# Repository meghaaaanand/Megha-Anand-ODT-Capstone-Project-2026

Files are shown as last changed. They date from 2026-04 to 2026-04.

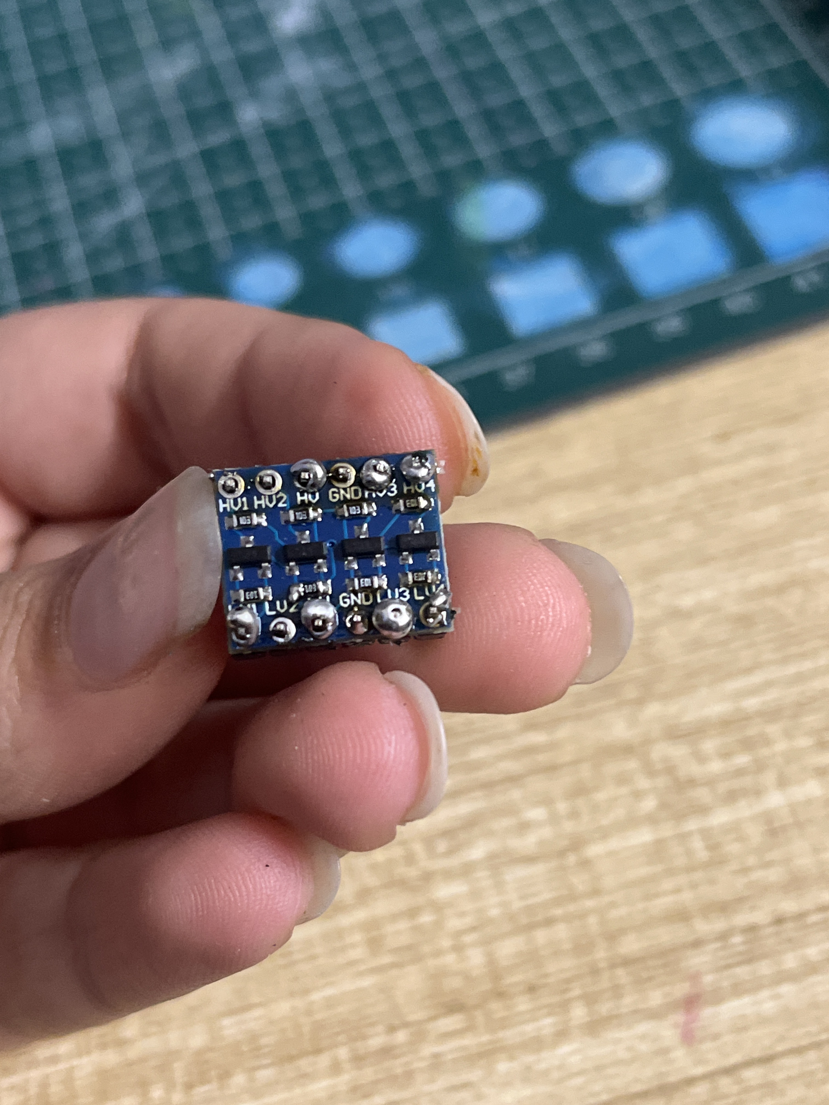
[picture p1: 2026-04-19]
Media/Week2/Pump Troubleshooting/1 Initial Logic Convertor solder.JPEG

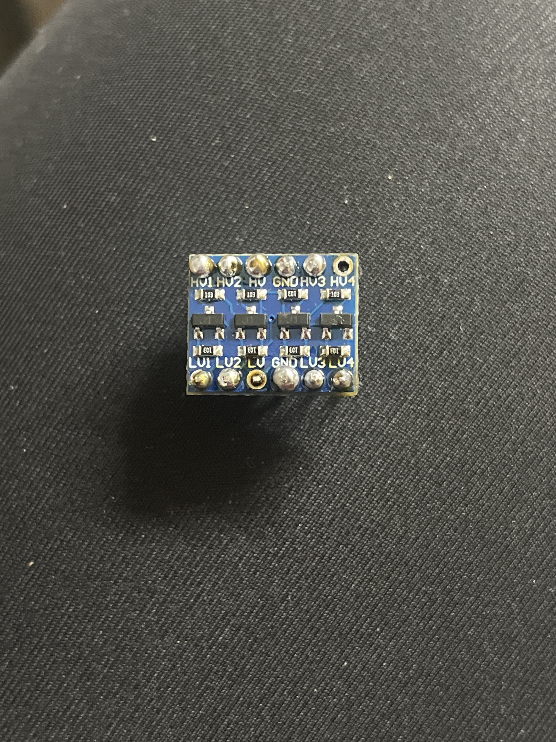
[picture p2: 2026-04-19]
Media/Week2/Pump Troubleshooting/2 Second solder.JPEG

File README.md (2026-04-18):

**Project Title**

Home Hydroponics System

**📌 Project Overview**

A compact vertical hydroponic system designed for home use, featuring a central pipe with angled plant spouts for efficient spatial distribution. Integrated perforated disc layers regulate staged water flow, improving nutrient delivery. Combined with embedded sensing and control, the system balances functionality, efficiency, and a clean, contemporary aesthetic.

**📂 Repository Structure**
1. Electronics Details
2. Mechanical Details
3. Software Details
4. Project Documents
5. Media

**⚙️ How to Navigate This Repository**

Electronics Details → Circuit Diagram, Components Justification

Mechanical Details → Sketches, CAD, and Fabrication Details

Software Details → Codes, Logic, and Implementation

Project Documents → Design thinking, Planning, Testing

Media → Weekly Progress and Final Output

**👥 Team Members**

Megha Anand & Siya Mittal

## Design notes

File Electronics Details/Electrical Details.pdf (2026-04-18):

# Electronic Details

## 1.Electronics Block Diagram

Attatched in seperate PDF file.

## 2.Components Table

Components | Quantity | Purpose | Justification
ESP32 | 1 | Central microcontroller to process sensor data and control system operations. | Provides sufficient GPIO pins, supports multiple sensors simultaneously, and enables real-time control (e.g., app/BLE integration).
Submersible Water Pump | 1 | Circulates nutrient-rich water through the hydroponic system. | Essential for maintaining continuous water flow, ensuring proper nutrient delivery to plants.
5V ,10A 1-Channel Relay Module | 1 | Switches the water pump ON/OFF using ESP32 signals. | Allows safe control of high-power devices (pump/mains) using low-voltage microcontroller output.
I2C Bi-Directional logic Level Converter- 4 Channel | 1 | Converts voltage levels between ESP32 (3.3V) and 5V components. | Prevents damage to ESP32 and ensures reliable communication with higher-voltage modules like the relay.
LDR Sensor | 3 | Detects light intensity at different levels of the structure. | Helps monitor light distribution across the system, enabling analysis of

| | | plant exposure and environmental conditions.
HC -SR04 | 1 | Measure water level in the reservoir. | Enables non -contact monitoring, preventing sensor damage and ensuring accurate water level detection.
DHT22 | 1 | Measures temperature and humidity of the environment. | Provides reliable environmental data critical for plant growth conditions.
Neo pixel | 1 | Provides visual feedback for system status (e.g., normal, warning, error). | Enhances user interaction and allows quick, intuitive understanding of system conditions without needing an interface.
Power Module | 1 | Supplies regulated power to components in the system. | Ensures stable voltage distribution, preventing fluctuations that could affect sensor readings and system reliability.

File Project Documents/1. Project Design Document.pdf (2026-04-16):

# Project Design Document

## 1. Design Intent

- What experience are you trying to create? : To create a low-effort, guided indoor growing experience where users can grow herbs and leafy greens in their apartments without needing prior knowledge or constant monitoring. The system should feel supportive and responsive, giving users feedback through both physical signals and a simple app interface.
- Who is it for? : People living in apartments or compact indoor spaces, including:
1. Beginners with no prior experience in growing plants
2. Users who want a low-maintenance system
3. Individuals who want to grow herbs or leafy greens at home

## 2. Inspiration & References

- Existing products / ideas : Click and Grow Smart Garden, AeroGarden, IKEA
- What did you learn from them? :
1. Simplicity is crucial — users prefer plug-and-play systems
2. Visual feedback (lights, indicators) makes systems more intuitive
3. Compact, aesthetic design is important for indoor environments
4. Automation reduces the barrier for beginners

Our system builds on this by adding modularity + real-time sensor-based feedback

## 3. User Journey

User starts…
The user sets up the hydroponic system in their apartment, arranges the modular pipes based on their space, and fills the water reservoir.

User interacts…
They power on the system and connect to the app created using MIT App Inventor. The app displays temperature, humidity, light levels, and water status.

System responds…
The ESP32 begins monitoring conditions and automatically runs the pump at intervals. The NeoPixel glows green, indicating everything is functioning normally.
User interacts…
Over time, the user occasionally checks the app. If environmental conditions change (e.g., temperature rises or water level drops), the system detects it.

System responds…
- If water is low → NeoPixel turns red + buzzer alert + app notification
- If conditions go out of ideal range → system adjusts pump activity and shows warning

User acts…
The user refills water or adjusts placement.

The system returns to normal operation. The experience becomes low-effort, guided, and interactive

## 4. Success Criteria

- Function :
1. Sensor readings update every 2–5 seconds
2. Pump responds automatically to system logic
3. Water level detection works within ±2–3 cm accuracy
4. Alerts trigger in under 1 second
- User Experience :
1. Sensor readings update every 2–5 seconds
2. Pump responds automatically to system logic
3. Water level detection works within ±2–3 cm accuracy
4. Alerts trigger in under 1 second
- Reliability :
1. System runs continuously without failure.
2. Stable sensor readings with minimal noise.
3. No water leakage or electrical issues.

## 5.System Overview

The project is a smart hydroponic system controlled by an ESP32 microcontroller. It collects environmental data using sensors and processes it to automate water flow and notify users of any issues. The system integrates both physical feedback (LED + buzzer) and a digital interface (mobile app).

- ESP32 (controller)
- Sensors:
1. DHT22 (temperature & humidity)
2. LDR (light detection)
3. HC-SR04 (water level)
- Water pump system
- NeoPixel LED
- Buzzer
- Modular 3D printed pipe structure
- Mobile app (MIT App Inventor)

## 6. High-Level Block Diagram

Attatched as a separate pdf below.

## 7. Input / Output Mapping

- Inputs :
1. DHT22 → temperature & humidity
2. LDR → ambient light levels
3. HC-SR04 → water level in reservoir
- Outputs :
1. Pump → controls water circulation
2. NeoPixel → visual system status
3. Buzzer → alert system
4. Mobile App → displays data + allows control

## 8. Sketches & Concepts

All sketches added in mechanical details section.

1. Initial pipe layouts (horizontal / vertical stacking options)
2. Reservoir placement ideas
3. Sensor placement (top, inside, side)
4. Modular connection mechanism (snap-fit / screw-fit)

## 9. Final System Architecture (Labelled)

Attatched as a separate pdf below.

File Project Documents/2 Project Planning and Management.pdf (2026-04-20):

## Project Planning & Management Document

1. Project Overview : A smart, modular hydroponic system for urban homes that automates plant care using an ESP32 microcontroller, real-time sensors, and a relay-controlled water pump. 3D printed modular pipes allow flexible, space-saving setup in any home environment. Monitor and control everything remotely through a companion mobile app, making home farming effortless and accessible.
2. Team Roles & Responsibilities
Member Name | Role | Responsibilities

Siya

Megha

App
software
developer

Coder

App layout and circuit
making, documentation

Coding and mechanism
structure, documentation
3. Project Timeline & Milestones
Week | Goals | Deliverables | Status

Week
0

Component
procurement +
Testing

Code Writing

Sketches

Blender models +
3d prints

App Layout

Motor
pump(readymade/
dc motor)

Final code

Sketches

Final hydroponic
pipe structure

App layout

Week
1

Final circuit
building

Integrating with
hydroponic
structure

Individual
component testing
within the
structure

App coding

Full working
hydroponic
structure

Complete working
app

### 4. Weekly Progress Log

Week 0

Planned Tasks: Research hydroponics automation system, gather all required components, plan circuit layout and assign sensor roles.

Completed Tasks: Researched ESP32 WROOM as the microcontroller, sourced components including DHT22, water level sensor, LDR, NeoPixel, buzzer, and pH sensor. Drafted initial wiring diagram and divided responsibilities among team members.

Challenges Faced: Difficulty deciding which sensors were essential vs optional within budget. Some components took time to source.

Solutions: Finalized component list based on project requirements. Ordered/borrowed all necessary parts and confirmed availability before proceeding.

Next Steps: Begin hardware assembly and test each sensor individually before full integration.

Week 1

Planned Tasks: Assemble the full circuit, connect all sensors to ESP32, begin writing and uploading code for each component.

Completed Tasks: Successfully wired DHT22 (temperature/humidity), water level sensor, LDR modules, pH sensor, NeoPixel LED, and buzzer to the ESP32. Wrote and tested individual sensor code. System was functioning on the original ESP32 unit.

Challenges Faced: Integrating multiple sensors simultaneously caused occasional read errors. NeoPixel required careful data pin handling due to 3.3V vs 5V logic differences.

Solutions: Added delays between sensor reads to avoid conflicts. Used a resistor on the NeoPixel data line to handle logic level difference. Confirmed stable readings across all sensors.

Next Steps: Test the full integrated system continuously, refine automation logic, and prepare for final demonstration.

Week 2

Planned Tasks: Run full system tests, finalize code, prepare documentation and demonstration.

Completed Tasks: Completed and finalized automation logic for the hydroponics system. Identified and resolved a critical hardware failure. Successfully restored full system functionality ahead of submission.

Challenges Faced: The original ESP32's USB port physically broke off, rendering it unusable. Replacement ESP32 units caused the onboard AMS1117 voltage regulator to overheat due to too many components drawing current from the 3.3V rail simultaneously (DHT22, water level sensor, LDRs, NeoPixel, and buzzer).

Solutions: Diagnosed the overheating as an overcurrent issue on the 3.3V rail. Resolved it by rewiring the NeoPixel and buzzer to the 5V/VIN pin instead of 3.3V, reducing the load on the AMS1117 regulator significantly. System stabilised and all sensors returned to normal operation.

Next Steps: Final submission — submit code, circuit diagram, and project documentation.

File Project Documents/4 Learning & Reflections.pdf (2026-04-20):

# Test Plan & Results

## 1. Team Reflection

How did the team work together?

- The team worked across hardware, coding, and design in parallel
- Strong collaboration during build phase, especially while assembling the final prototype

What worked well?

- Quick problem-solving under pressure
- Supportive teamwork during last-minute failures
- Ability to pivot and still present the system logic clearly

What could be improved?

- Lack of redundancy planning (no backup microcontroller)
- Over-reliance on a single working setup
- Final testing should have been done earlier to avoid last-day risks

## 2. Technical Reflection

Key Technical Challenges

- Sensor inconsistencies (DHT22, ultrasonic)
- Managing multiple components on ESP32
- Relay control and power handling

Critical Failure

- On the day of submission, the ESP32 power port broke, causing the full system to stop working
- This highlighted a major gap in hardware robustness and backup planning

What did you learn (Hardware/Software)?

- Hardware is as fragile as code is flexible
- Importance of strain relief, proper mounting, and secure connections
- Always design systems with fail-safes and backups

Mistakes & Debugging Experiences

- Focused heavily on functionality, less on durability
- Did not anticipate physical wear/failure points
- Learned that a working prototype ≠ a reliable product

## 3. Design Reflection

Did the experience match your intention?

- Conceptually, the system achieved:
- Smart monitoring
- Improved water distribution
- Home-friendly design intent
- However, execution did not fully hold under real-world conditions

What would you improve?

- Design for durability, not just functionality
- Integrate casing/enclosure for electronics
- Make system more robust and product-like, not prototype-like

User Feedback Insights

- Users appreciated automation and simplicity
- Strong reliance on visual cues over data
- Highlighted need for clearer, more intuitive feedback

## 4. Personal Reflection

What I learned

- Real-world systems fail in unpredictable ways
- The importance of designing for failure, not just success
- Integration of hardware + software + design is complex but powerful

What I struggled with

- Managing last-minute technical breakdown
- Dealing with the gap between a working prototype and a failed final demo
- Balancing ambition with practical constraints

What I am proud of

- Building a fully conceptualized smart hydroponic system
- Understanding the system deeply enough to explain it even without a working demo
- Turning a failure into a strong learning outcome

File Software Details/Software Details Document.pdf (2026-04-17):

# Software Documentation

## 1. Software Overview

What does the software do? : The software controls and monitors a smart hydroponic system using an ESP32 microcontroller. It continuously collects data from multiple sensors including temperature, humidity, water level, and light intensity, and evaluates system conditions in real time.

Based on predefined thresholds, the system classifies the environment into three states:

- Good – optimal conditions
- Warning – conditions nearing limits
- Trouble – unsafe conditions or sensor failure

The system provides real-time feedback through:

- NeoPixel LED ring (visual indication)
- Buzzer (audio alerts)

Additionally, the system transmits live sensor data and system status to a mobile application via Bluetooth Low Energy (BLE), enabling remote monitoring.

Platform used :

- MicroPython : Used for programming the ESP32
- MIT APP Inventor : Used for developing the mobile app interface
- Bluetooth Low Energy : Used for communication between ESP32 and app

## 2. System Logic

System Flow:

1. The ESP32 initializes sensors and Bluetooth connection.

2. The system continuously reads:
a. Temperature and humidity (DHT22)
b. Water level (Ultrasonic sensor)
c. Light levels (LDR sensors)
3. The sensor data is compared with predefined threshold values.
4. The system determines the condition:
a. If values are outside safe range → Trouble code initiated
b. If values are near limits → Warning code initiated
c. Otherwise → Good code initiated
5. Based on the condition:
a. LEDs change color (Green / Yellow / Red)
b. Buzzer activates for alerts
6. The system formats all sensor data into a string.
7. Data is transmitted to the mobile app via BLE.
8. The loop repeats continuously for real-time monitoring.

## 3. Flowchart

Sperate PDF attached

## 4. App Flow (If MIT App Inventor)

Screen Flow:

- Main screen displays:
1) Temperature
2) Humidity
3) Water level
4) Light status
5) System status
- Connect Button : Establishes BLE connection with ESP32
- Data Flow:
1. ESP32 sends sensor data via BLE
2. The app receives the data string

3. The string is parsed into individual values
4. Values are displayed on the screen in real time

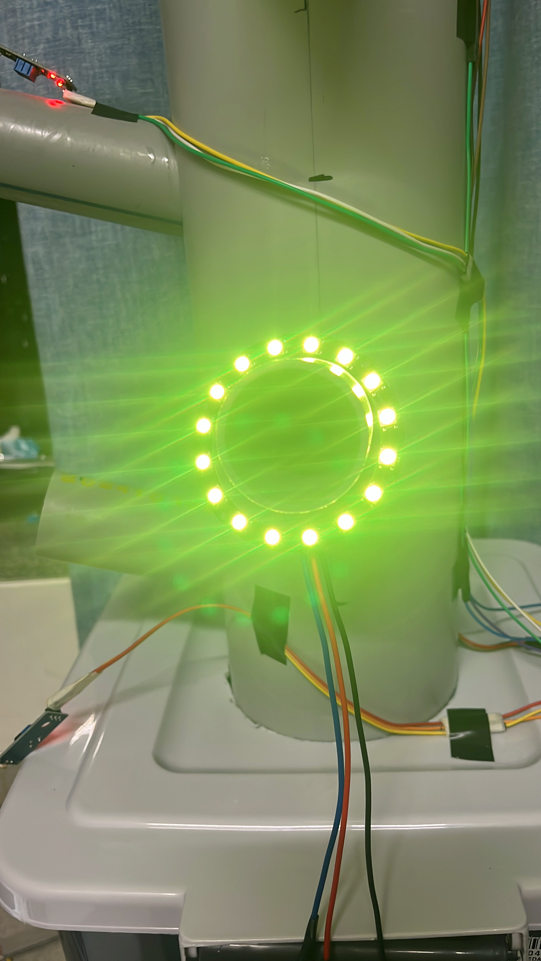
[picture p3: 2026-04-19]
Media/Week2/Adding Electronics to Hydroponic Structure/12 Neopixel.JPG

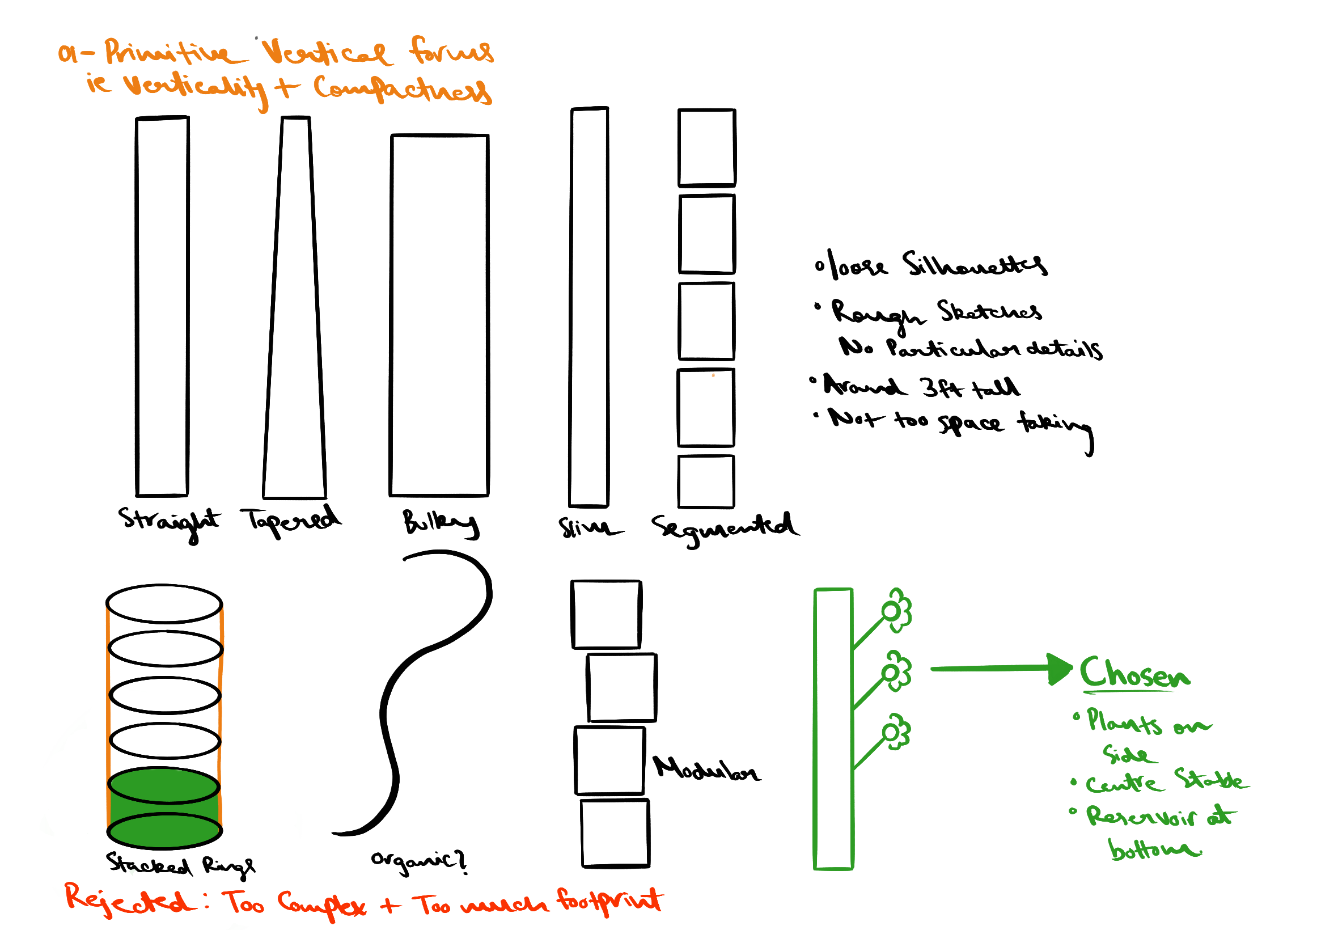
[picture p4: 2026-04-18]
Mechanical Details/Sketches/Central Pipe and system basic forms.png

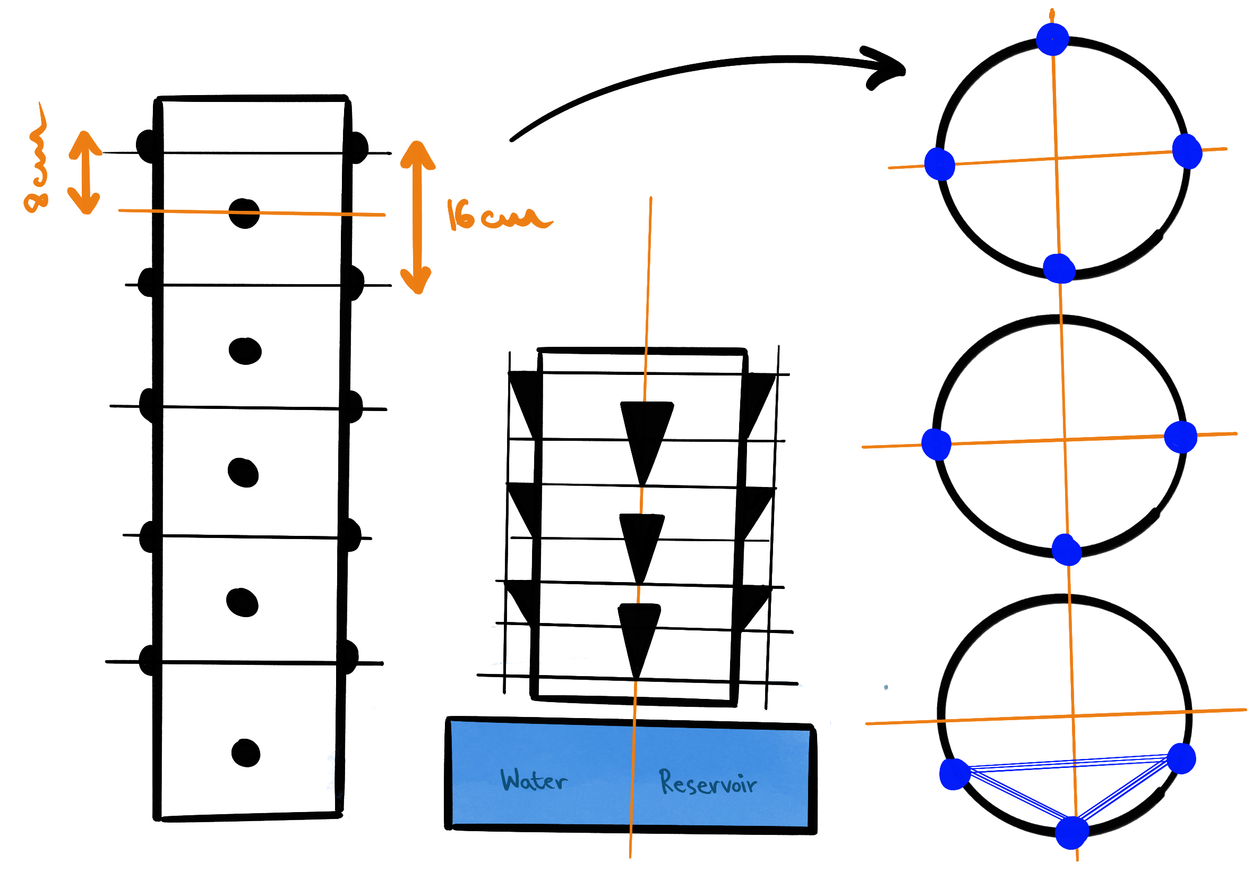
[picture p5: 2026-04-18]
Mechanical Details/Sketches/Structure Basic sketch w rough dimensions.png

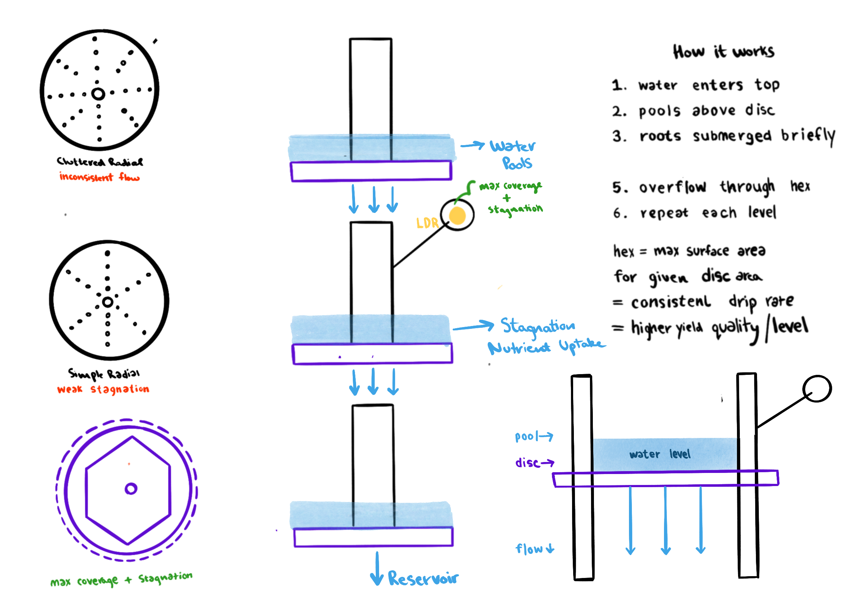
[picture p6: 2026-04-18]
Mechanical Details/Sketches/Dividing Disc Design and Function.png

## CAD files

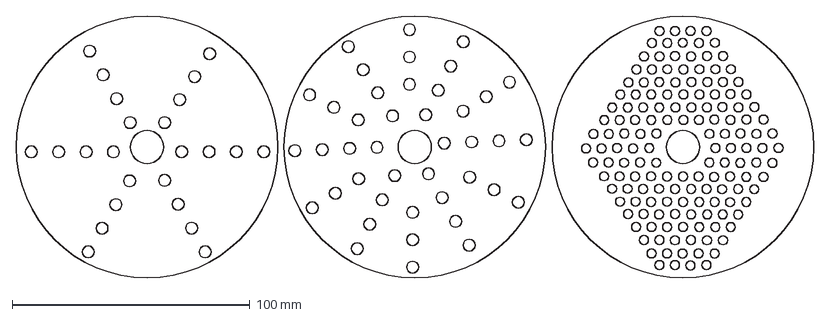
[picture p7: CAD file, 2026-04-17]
Mechanical Details/Disc Patterns.dxf
335.2 x 110.0 mm

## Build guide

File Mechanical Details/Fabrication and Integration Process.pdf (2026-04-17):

# Fabrication and Integration Process

## 1. Material Choice Justification :

Primary Structure: PVC Pipes (Polyvinyl Chloride Pipes)

The hydroponic system was constructed entirely using PVC pipes and a plastic reservoir. PVC was chosen as the primary material due to its high resistance to water exposure, making it suitable for a system that operates continuously with circulating water.

Unlike materials such as MDF, which are prone to swelling and degradation when exposed to moisture, PVC remains structurally stable and does not corrode. Additionally, since the system is intended for semi-outdoor use, PVC provides durability under sunlight and environmental conditions.

The reservoir was created using a plastic dustbin, selected for its availability, waterproof nature, and sufficient volume capacity.

Why not Acrylic / MDF?

Acrylic and MDF were not used in the main structure due to functional limitations:

- MDF is not water-resistant and can deteriorate quickly in humid or wet environments.
- Acrylic, while water-resistant, was not structurally necessary for this system and would have added complexity without significant functional benefit.

However, MDF was used for laser-cut demonstration samples, as it is easy to cut, cost-effective, and suitable for quick prototyping and showcasing scaled components.

Environmental Considerations

Since the system involves continuous water flow and is intended for open or semi-open environments, material selection was influenced by:

- Resistance to water damage
- Durability under sunlight exposure
- Structural stability over time

PVC effectively meets all these requirements, making it an appropriate choice for the system.

## 2. Fabrication Steps :

### 1. Preparation of Main Structure

A central PVC pipe of 110 mm diameter was used as the primary vertical structure. Holes were marked and drilled along the length of the pipe to insert plant holders.

Due to tool limitations, holes were initially drilled at 35 mm diameter and then manually filed to approximately 40 mm to achieve the required fit.

This process involved multiple iterations to ensure proper alignment and fitting of components.

### 2. Preparation of Plant Holders

Secondary PVC pipes of 40 mm diameter were cut into segments of approximately 13 cm length. These segments act as holders for plant growth.

Each segment was inserted into the manually enlarged holes on the main pipe to create a modular planting structure.

### 3. Reservoir Fabrication

A plastic dustbin was repurposed as the water reservoir. A 110 mm diameter hole was cut into the lid/body to allow insertion of the main vertical pipe.

This ensured a stable connection between the structure and the water source.

### 4. Assembly

The smaller PVC pipe segments were fixed into the main pipe using adhesive (Feviquick). This step required careful alignment to maintain overall structural balance.

Due to manual filing and fitting, some irregularities occurred; however, the structure remained stable and functional.

### 5. Iteration & Challenges

- Achieving the correct hole size required trial and error during filing
- Some components were slightly misaligned due to manual fabrication
- Structural imperfections were present but did not affect overall stability or functionality

### 6. Electronics Integration

Electronics were integrated after the physical structure was assembled.

Challenges faced:

- Managing wiring across a tall vertical structure
- Ensuring sufficient wire length for sensor placement
- Organizing components without interfering with water flow

Adjustments were made to accommodate wiring distribution across the system.

### 7. Prototyping (Laser Cutting)

Laser cutting was used to create scaled demonstration samples of ring components using MDF.

This allowed quick visualization and testing of form and proportions before or alongside physical fabrication.

The fabrication process involved iterative problem-solving, adapting to tool and material constraints while maintaining functionality and structural stability.

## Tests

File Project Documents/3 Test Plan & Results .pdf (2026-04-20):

# Test Plan & Results

## 1. Test Plan

Objective: Evaluate system performance, usability, and reliability of the HydraFlow hydroponic setup in a home-like environment.

What was tested:

- Sensor accuracy (DHT22, LDR, ultrasonic water level)
- Pump automation via relay
- Water distribution efficiency (disc stagnation system)
- App interface usability (MIT App Inventor)
- Overall system stability (continuous operation)

Testing Conditions:

- Indoor simulated home environment
- Continuous run cycles (2–4 hours)
- Manual vs automated comparisons for water flow

## 2. User Testing

Who were the users?

- 3–5 participants
- Mix of:
- Beginners (no hydroponics experience)
- Design students (familiar with systems thinking)
- Tech-aware users

What tasks were given?

- Set up and understand the system (basic onboarding)
- Check real-time stats on the app (temp, humidity, water level)

- Turn pump ON/OFF using the app
- Interpret system states (Good / Warning / Trouble via LEDs/buzzer)
- Observe plant water distribution across levels

## 3. Results

System Performance:

- Sensors provided consistent real-time data (minor fluctuations)
- Relay successfully controlled pump via ESP32
- Disc system improved water reach across all levels

Usability:

- Users could navigate app easily after brief guidance
- Visual feedback (Neopixel + buzzer) improved understanding

Efficiency:

- More uniform water distribution vs traditional vertical systems
- Reduced dry spots in upper layers

## 4. Observations

User Behavior

- Users relied heavily on visual feedback (LEDs) over numerical data
- Preferred quick status indicators instead of reading values
- Hesitated initially but gained confidence quickly

Pain Points

- Confusion in interpreting raw sensor values (e.g., humidity %)
- Delay in understanding warning vs trouble states
- App UI felt basic / slightly cluttered
- Initial setup required guidance (not fully plug-and-play yet)

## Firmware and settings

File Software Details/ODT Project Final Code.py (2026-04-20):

#Import all modules ie neopixel, dht, from machine import pin, time, machine in general
# SENSORS USED ::::: Temperature, Ultrasonic for water level, LDR, Humidity, PH sensor probe (IDEALLY)
# APP Interface along with it :::Digitally monitor, Water level of reservoir, TEMP, HUMIDITY, LIGHT RECEIVED, WHEN WAS IT LAST WATERED.
#Time.ticks continous timer or timer in app

import machine
from machine import Pin, time_pulse_us
import neopixel
import time
import dht
import bluetooth
import random
#coding for relay module how does it work


conn_handle = None
value = ""
name = "Megha ESP32" #Name of Your ESP32 (Change it to avoid Confusion)
ble = bluetooth.BLE()

ble.active(False)
time.sleep(0.5)
ble.active(True)
ble.config(gap_name=name)

service_UUID = bluetooth.UUID("6e400001-b5a3-f393-e0a9-e50e24dcca9e")
char_UUID = bluetooth.UUID("6e400002-b5a3-f393-e0a9-e50e24dcca9e")

char = (char_UUID, bluetooth.FLAG_READ | bluetooth.FLAG_NOTIFY)
service = (service_UUID, (char,),)
((char_handle,),) = ble.gatts_register_services((service,))

def event_occured(event, data):
    global conn_handle 
    if event == 1:
        conn_handle = data[0]
        print("Connected")
    elif event == 2:
        conn_handle = None
        print("Disconnected")
        advertise(name)
                  
def advertise(device_name):
    name_bytes = device_name.encode()
    flags = bytearray([0x02, 0x01, 0x06])
    short_name = bytearray([len(name_bytes) + 1, 0x08]) + name_bytes
    full_name = bytearray([len(name_bytes) + 1, 0x09]) + name_bytes
    adv_data = flags + short_name + full_name
    ble.gap_advertise(50, adv_data=adv_data)
    print("Awating Connection...Advertising as:", device_name)


#for ultrasonic sensor : Brown = VCC, Grey = GND, White = Echo , Black = Trig 
neo = neopixel.NeoPixel(Pin(12),16)
temphumi = dht.DHT22(Pin(14))
buzz = Pin(4,Pin.OUT)
trig = Pin(18, Pin.OUT)
echo = Pin(23, Pin.IN)
ldr1 = Pin(25, Pin.IN, Pin.PULL_UP) #top on circuit
ldr2 = Pin(32, Pin.IN, Pin.PULL_UP) #bottom on circuit
ldr3 = Pin(34, Pin.IN, Pin.PULL_UP) # middle circuit

for i in range(16):
    neo[i] = (0,0,0)
neo.write()
time.sleep(1)



#def functions for : Temp and Humidity Sensor (20 to 25 degree celsius) , Ultrasonic for water level, LDR (time ticks until 5-6 hours)

#alert when temp, humidity, and water level go haywire.

def TH() :
    try:
        temphumi.measure() 
        temp = temphumi.temperature() 
        hum = temphumi.humidity()
        print(temp)
        print(hum)
        return temp, hum

    except OSError:
        print("Failed to read from sensor")
        return -100, -100

    
def waterlevel():
    trig.off()
    time.sleep_us(2)
    trig.on()
    time.sleep_us(10)
    trig.off()
    duration = time_pulse_us(echo, 1, 30000)  # 30 ms timeout
    if duration < 0:
        print("No object detected (Timeout)")
        return 100
    else:
        distance = duration / 58
        print("Distance:", distance, "cm")
        return distance
    
    
def ldrtop():
    lightval1 =ldr1.value()
    return lightval1
    #if lightval1 == 0 light detected

def ldrmiddle():
    lightval3 =ldr3.value()
    return lightval3
    #if lightval1 == 0 light detected

def ldrbottom():
    lightval2 =ldr2.value()
    return lightval2
    #if lightval1 == 0 light detected
    
def sysgood():
    for i in range(16):
        neo[i] = (0,255,0)
    neo.write()
    buzz.off()
    
def syswarning():
    for i in range(16):
        neo[i] = (255,255,0)
    neo.write()
    buzz.on()
    time.sleep(0.2)
    buzz.off()
    time.sleep(0.5)
        
def systrouble():
    for i in range(16):
        neo[i] = (255,0,0)
    neo.write()
    buzz.on()
    time.sleep(0.2)
    buzz.off()
    time.sleep(0.1)
    
    
    

while True:
    ble.irq(event_occured)
    advertise(name)
    temp, hum = TH()
    water = waterlevel()
    top = ldrtop()
    middle = ldrmiddle()
    bottom = ldrbottom()

    # count light sensors detecting light
    ldrcount = 0
    if top == 0:
        ldrcount = ldrcount + 1
    if middle == 0:
        ldrcount = ldrcount + 1
    if bottom == 0:
        ldrcount = ldrcount + 1

#trouble conditions red beep beep 
    if temp == -100 or hum == -100:
        systrouble()
        status = "TROUBLE : DHT sensor not working!"

    elif temp < 18:
        systrouble()
        status = "TROUBLE : Temperature below recommended! "
        
    elif temp > 30:
        systrouble()
        status = "TROUBLE : Temperature above recommended! "

    elif hum < 40:
        systrouble()
        status = "TROUBLE : Humidity below recommended!"
        
    elif hum > 80:
        systrouble()
        status = "TROUBLE : Humidity above recommended!"

    elif water > 25:
        systrouble()
        status = "TROUBLE : Low water level! Please Refill!"

    elif ldrcount == 0:
        systrouble()
        status = "TROUBLE : No light being received!"

#warning condition yellow
    elif (18 <= temp < 20):
        syswarning()
        status = "WARNING : Temperature about to go below recommended!"
        
    elif (28 < temp <= 30):
        syswarning()
        status = "WARNING : Temperature about to go above recommended!"

    elif (40 <= hum < 45):
        syswarning()
        status = "WARNING : Humidity about to go below recommended!"
    
    elif (75 < hum <= 80):
        syswarning()
        status = "WARNING : Humidity about to go above recommended!"

    elif water > 20:
        syswarning()
        status = "WARNING : Water level about to go down!"

    elif ldrcount == 1 or ldrcount == 2:
        syswarning()
        status = "WARNING : Partial light on hydroponic system!"

    # GOOD CONDITION
    else:
        sysgood()
        status = "GOOD"

    print("Ambient Temperature :", temp)
    print("Ambient Humidity:", hum)
    print("Water Level:", water)
    print("Top:", top, "Middle:", middle, "Bottom:", bottom)
    print("System Status:", status)

    data = "Ambient Temperature :{}, Ambient Humidity :{},Water Level :{:.2f},Top LDR :{},Middle LDR :{},Bottom LDR :{},System Status :{}".format(
        temp, hum, water, top, middle, bottom, status
    )

    ble.gatts_write(char_handle, data.encode())

    if conn_handle is not None:
        ble.gatts_notify(conn_handle, char_handle)
    
    time.sleep(1)

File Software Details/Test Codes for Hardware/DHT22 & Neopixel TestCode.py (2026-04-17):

import dht
import machine
from machine import Pin
import time
import neopixel

temphumi = dht.DHT22(Pin(14))
neo = neopixel.NeoPixel(Pin(12),16)

while True:
    try:
        temphumi.measure()  # take reading

        temp = temphumi.temperature()   # in °C
        hum = temphumi.humidity()
        print(temp)
        print(hum)
        time.sleep(0.2)
        if temp<27 and hum < 66:
            for i in range(16):
                neo[i] = (0,255,0)
                neo.write()
                time.sleep(0.1)
            for i in range(16):
                neo[i] = (0,0,0)
                time.sleep(0.1)
                neo.write()
        else :
            for i in range(16):
                neo[i] = (255,0,0)
                neo.write()
                time.sleep(0.1)
            for i in range(16):
                neo[i] = (0,0,0)
                time.sleep(0.1)
                neo.write()

    except OSError:
        print("Failed to read from sensor")

    time.sleep(2)
